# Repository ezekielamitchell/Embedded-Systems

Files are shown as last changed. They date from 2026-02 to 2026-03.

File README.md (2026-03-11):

# REDHAWK ESP32 Robot

Custom PCB-based robot designed and built for the Seattle University Embedded Systems & Design course. The board centers on an ESP32 microcontroller and includes motor drive, quadrature encoders, distance sensing, line following, ambient light sensing, audio output, and Wi-Fi. This repository contains the full KiCad hardware design, power-on functional test firmware, and supporting documentation.

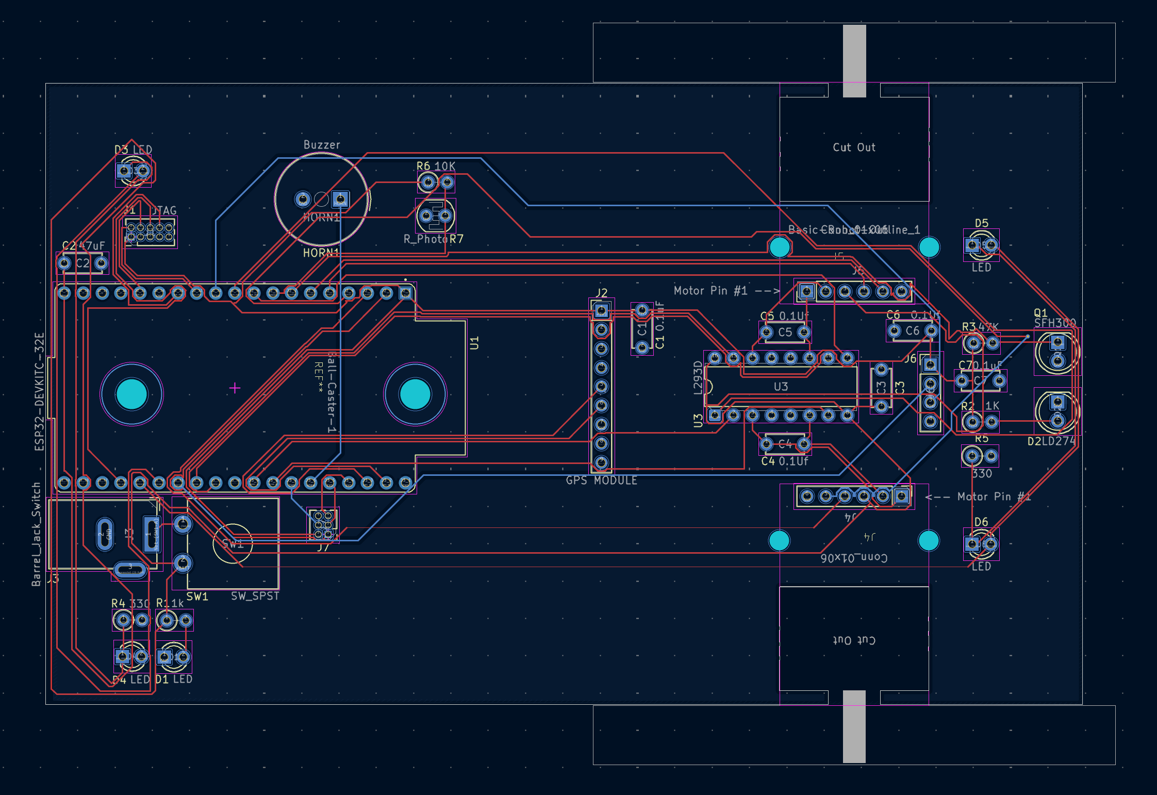
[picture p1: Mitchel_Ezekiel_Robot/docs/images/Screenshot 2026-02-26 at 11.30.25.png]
PCB Layout


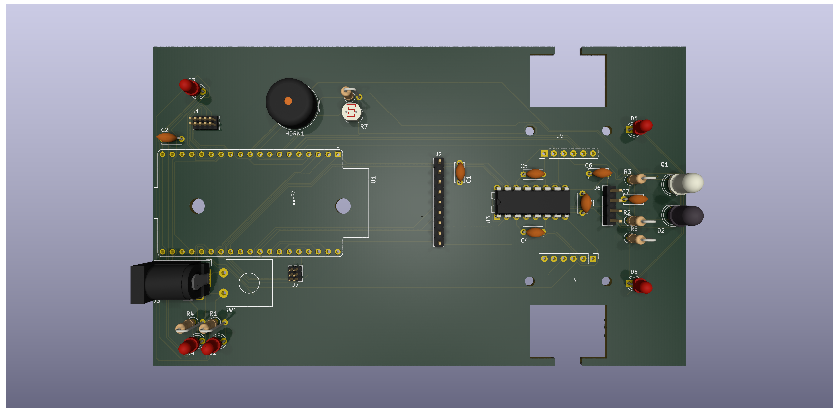
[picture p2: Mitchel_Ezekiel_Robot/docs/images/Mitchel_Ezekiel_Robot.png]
PCB 3D Render — Top


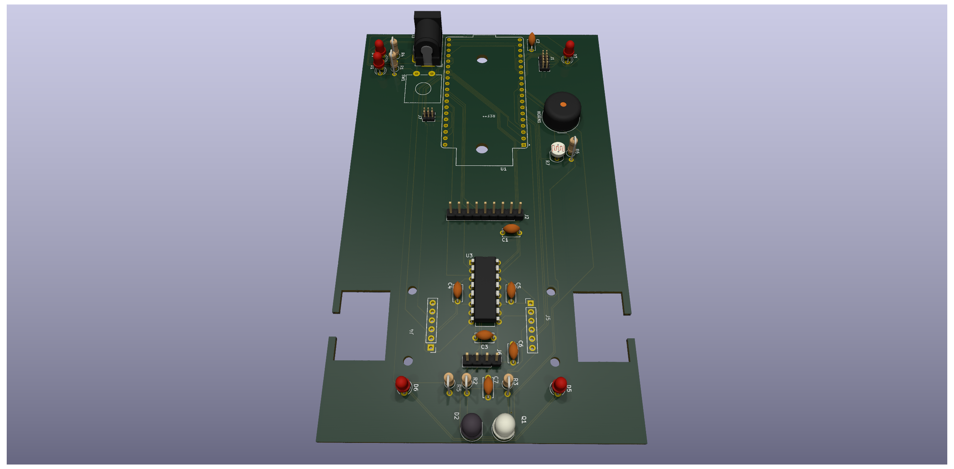
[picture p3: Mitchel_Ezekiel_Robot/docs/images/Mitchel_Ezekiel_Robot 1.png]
PCB 3D Render — Perspective


---

## Repository Structure

```
Embedded-Systems/
├── Mitchel_Ezekiel_Robot/       # KiCad PCB and schematic project
├── PowerOn_Functional_Test/     # PlatformIO firmware — hardware self-test
└── Interrupts/                  # Interrupt lab (placeholder)
```

---

## PCB Design

KiCad 9.0 project containing the full schematic and two-layer PCB layout.

```
Mitchel_Ezekiel_Robot/
├── Mitchel_Ezekiel_Robot.kicad_pcb
├── Mitchel_Ezekiel_Robot.kicad_sch
├── Mitchel_Ezekiel_Robot.kicad_pro
├── Mitchel_Ezekiel_Robot.kicad_prl
├── Ezekiel_Mitchell_ESP32_Robot_Schematic.kicad_pro
├── sym-lib-table
├── docs/
│   ├── ESP32EmeddedRobot_Design-GetStarted-v00-1-10-2025a.pdf
│   └── images/
├── deliverables/
│   └── Ezekiel_Mitchell_ESP32_Robot_Schematic.kicad_sch
└── downloadables/
    ├── 0-My_Library.kicad_sym
    └── 0-My-Library.pretty/
```

### Hardware Overview

#### Microcontroller

| Part | Description |
|---|---|
| ESP32-DEVKITC-32E (U1) | Main MCU — dual-core Xtensa LX6, Wi-Fi + Bluetooth |

#### Motor Drive

| Part | Description |
|---|---|
| L293D (U3) | Dual H-bridge motor driver (DIP-16) |
| Pololu-3675 | Gear motors with quadrature encoders (x2) |
| Pololu-2691 / Ball-Caster-1 | Ball caster (rear support) |

#### Sensors and I/O

| Part | Description |
|---|---|
| R7 — R_Photo | LDR photoresistor (ambient light sensing) |
| D2 — LD274 | IR LED emitter (line detection) |
| Q1 — SFH300 | IR phototransistor receiver |
| HC-SR04 | Ultrasonic distance sensor (TRIG / ECHO) |
| HORN1 — Buzzer | Audio feedback (TDK PS1240P02BT) |
| D1, D3-D6 — LED | Status indicator LEDs (x5, 3 mm) |
| SW1 — SW_SPST | Tactile on/off switch |

#### Communication and Debug

| Part | Description |
|---|---|
| J2 — GPS MODULE | GPS module connector (UART: GPS_TX / GPS_RX) |
| J1 — JTAG | 1.27 mm 2x5 JTAG/SWD debug header |

#### Connectors

| Ref | Value | Description |
|-----|---|---|
| J3 | Barrel_Jack_Switch | Battery input (horizontal barrel jack) |
| J4 | Conn_01x06 | General 6-pin header |
| J5 | Conn_01x06 | General 6-pin header |
| J6 | Conn_01x04 | General 4-pin header |
| J7 | Conn_02x03_Odd_Even | Motor / encoder connector (2x3) |

#### Passives and Power

| Ref | Value | Notes |
|-----|---|---|
| C1, C5-C7 | 0.1 uF | Decoupling capacitors |
| C2, C3 | 47 uF | Bulk filter capacitors |
| R1, R2 | 1 kOhm | Pull-up / current limiting |
| R3 | 47 kOhm | Pull-up for IR receiver circuit |
| R4, R5 | 330 Ohm | LED current limiting |
| R6 | 10 kOhm | Voltage divider (LDR / sensor bias) |

Power rails: `+BATT` (battery input), `+3V3` (regulated 3.3 V from ESP32 module)

### PCB Net Classes

| Net Class | Track Width | Via Diameter | Via Drill | Notes |
|---|---|---|---|---|
| Power | 0.5 mm | 1.0 mm | 0.5 mm | VCC, GND rails |
| Motor | 0.8 mm | 1.2 mm | 0.6 mm | H-bridge output lines |
| High Speed / GPS | 0.2 mm | 0.8 mm | 0.4 mm | GPS UART, high-frequency signals |
| Default | 0.2 mm | 0.8 mm | 0.3 mm | General signals |

### Custom Libraries

Symbol library: `downloadables/0-My_Library.kicad_sym`
Footprint library: `downloadables/0-My-Library.pretty/`

Included footprints:

- `MODULE_ESP32-DEVKITC-32E`
- `Pololu-3675-GearMotorWEncoder`
- `Pololu-2691-Ball_Caster` / `Ball-Caster-1`
- `Basic-Robot-Outline_1`
- ECE capacitive and piano touch switch footprints
- `BAT_2481`, `TRIM_PTA3043-2015DPA104`, and others

### Getting Started (PCB)

1. Install [KiCad 9.0](https://www.kicad.org/)
2. Clone this repository
3. Open `Mitchel_Ezekiel_Robot/Mitchel_Ezekiel_Robot.kicad_pro` in KiCad
4. Register the custom libraries in KiCad's library manager:
   - Footprint: `downloadables/0-My-Library.pretty`
   - Symbol: `downloadables/0-My_Library.kicad_sym`
5. Refer to `docs/ESP32EmeddedRobot_Design-GetStarted-v00-1-10-2025a.pdf` for the original design brief

---

## Power-On Functional Test Firmware

PlatformIO/Arduino firmware that exercises every major peripheral in a fixed sequential test sequence. Flash once and observe the serial monitor for pass/fail output. Tests run in `setup()`; `loop()` serves the Wi-Fi web control interface.

```
PowerOn_Functional_Test/
├── platformio.ini       # PlatformIO config (espressif32 >= 6.0.0)
└── src/
    ├── config.h         # Pin definitions, PWM parameters, Wi-Fi credentials
    ├── main.cpp         # Test sequence and hardware helpers
    ├── web_control.h    # Web server public API
    └── web_control.cpp  # HTTP route handlers and web control page
```

### Prerequisites

| Requirement | Details |
| --- | --- |
| PlatformIO | [platformio.org](https://platformio.org) or VS Code extension |
| ESP32-DevKitC | Connected via USB |
| Arduino-ESP32 core v3.x | Pulled in automatically by `espressif32@^6.0.0` |
| Assembled robot PCB | Motors, LEDs, horn, and sensors populated |

### Pin Map

| Signal | GPIO | Notes |
| --- | ---- | ----- |
| Right Motor 1A / 2A | 18, 19 | L293D direction pins |
| Right Motor EN1 (PWM) | 26 | L293D enable — speed control |
| Left Motor 3A / 4A | 16, 17 | L293D direction pins |
| Left Motor EN3 (PWM) | 25 | L293D enable — speed control |
| Right Encoder A / B | 36, 39 | Input-only GPIOs, INPUT_PULLUP |
| Left Encoder A / B | 34, 35 | Input-only GPIOs, INPUT_PULLUP |
| Horn (piezo) | 21 | PWM — 1 kHz, 50% duty |
| Front LEDs | 2 | Bootstrap pin, safe as output after boot |
| Rear LEDs | 0 | Bootstrap pin, safe as output after boot |
| Photoresistor | 33 | ADC1_CH5 — 12-bit analog input |
| IR Line Sensor | 32 | Digital input |
| Ultrasonic TRIG / ECHO | 4, 27 | HC-SR04 |
| Status LED | 5 | Blinks during Wi-Fi connect, solid when connected |

### Test Sequence

| # | Test | Description | Pass Criteria |
|---|---|---|---|
| 1 | Horn | 5 slow beeps (400 ms on / 300 ms off) | Audible beeps |
| 2 | Front LEDs | 5 blinks on GPIO 2 | Visible flashes |
| 3 | Rear LEDs | 5 blinks on GPIO 0 | Visible flashes |
| 4 | Left Motor | Forward at 100% duty for 1 s | Wheel spins |
| 5 | Right Motor | Forward at 100% duty for 1 s | Wheel spins |
| 6 | Ultrasonic | 5 distance readings via HC-SR04 | At least one valid echo |
| 7 | IR / Line Sensor | Waits up to 10 s for signal transition (user interaction) | Transition detected |
| 8 | Photoresistor | 60 s day/night monitor — lamps follow light level (user interaction) | Lamps respond |
| 9 | Completion | 15 fast beeps as end-of-test signal | Audible beeps |
| EC | Wi-Fi + Web Server | Connects to configured SSID; starts HTTP control page | IP printed to serial |

Tests 7 and 8 require manual interaction. Listen for the two-beep prompt before covering or uncovering the respective sensor.

The web control page (extra credit) is served at the board's IP address after Wi-Fi connects. It displays test results and provides buttons to trigger the horn, toggle LEDs, and drive the motors.

### Build and Flash

Set Wi-Fi credentials in `src/config.h` before flashing:

```cpp
#define WIFI_SSID "your-network-name"
#define WIFI_PASS "your-password"
```

```bash
pio run                   # build
pio run --target upload   # build and flash
pio device monitor        # serial monitor at 115200 baud
```

VS Code: use the PlatformIO toolbar — Build, Upload, Monitor.

---

## Author

Ezekiel Mitchell — Seattle University, Embedded Systems & Design

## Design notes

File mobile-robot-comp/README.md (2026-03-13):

# Robot Firmware — Combined

Unified firmware for the REDHAWK ESP32 robot. Covers all functional tests, a Wi-Fi web control panel for driver mode, and two autonomous modes (line following + maze speed run).

> **Course:** ECEGR 3210 — Embedded Systems & Design, Seattle University, March 2026
> **Author:** Ezekiel A. Mitchell

---

## Features at a Glance

| Feature | Description |
| --- | --- |
| 7 Functional Tests | Horn, LEDs, Light Sensor, Motors, Line Sensor, Ultrasonic, Completion |
| Driver Mode | Hold-to-drive web UI with speed slider and live sensor panel |
| Line Follow (Autonomous) | Single-sensor left-edge follower — BANN 201 circuit |
| Maze Solve (Autonomous) | Right-hand-rule with front ultrasonic — BANN 207 speed run |
| Serial Menu | Full test and mode control at 115200 baud |

---

## Prerequisites

| Requirement | Details |
| --- | --- |
| **PlatformIO** | VS Code extension or CLI from [platformio.org](https://platformio.org) |
| **ESP32-DevKitC** | Connected via USB |
| **arduino-esp32 v3.x** | Pulled in automatically by `espressif32@^6.0.0` in `platformio.ini` |
| **Assembled robot PCB** | Motors, LEDs, horn, and all sensors populated and wired |

---

## Project Structure

```text
PowerOn_Functional_Test/
├── platformio.ini        PlatformIO project config
└── src/
    ├── config.h          Pin assignments, PWM constants, autonomous tuning
    ├── web_control.h     Shared RobotMode enum + extern declarations
    ├── web_control.cpp   All HTTP route handlers and unified web UI
    └── main.cpp          Motor helpers, test functions, autonomous algorithms
```

---

## Hardware & Pin Map

| Signal | GPIO | Direction | Notes |
| --- | --- | --- | --- |
| Right Motor 1A | 18 | Output | L293D pin 2 — direction |
| Right Motor 2A | 19 | Output | L293D pin 7 — direction |
| Right Motor EN1 (PWM) | 26 | Output | L293D pin 1 — speed, LEDC ch 1 |
| Left Motor 3A | 16 | Output | L293D pin 10 — direction |
| Left Motor 4A | 17 | Output | L293D pin 15 — direction |
| Left Motor EN3 (PWM) | 25 | Output | L293D pin 9 — speed, LEDC ch 2 |
| Right Encoder A / B | 36, 39 | Input | Input-only GPIOs, INPUT_PULLUP |
| Left Encoder A / B | 34, 35 | Input | Input-only GPIOs, INPUT_PULLUP |
| Horn (piezo) | 21 | Output | PWM 1 kHz, 50% duty, LEDC ch 0 |
| Front LEDs | 2 | Output | Bootstrap pin — safe after boot |
| Rear LEDs | 0 | Output | Bootstrap pin — safe after boot |
| Light Sensor (LDR) | 33 | Analog In | ADC1_CH5, 12-bit (0–4095) |
| IR Line Sensor | 32 | Digital In | LOW = on black line (default) |
| Ultrasonic TRIG | 4 | Output | HC-SR04 trigger |
| Ultrasonic ECHO | 27 | Input | HC-SR04 echo |
| Status LED | 5 | Output | Solid = Wi-Fi connected |

---

## Configuration

All pin assignments and tuning constants are in `src/config.h`.

**Wi-Fi credentials:**

```cpp
#define WIFI_SSID "SU-ECE-LAB"
#define WIFI_PASS "FaraDay8086!"
```

**Autonomous tuning** (adjust to match your robot's physical characteristics):

```cpp
#define LINE_DETECT_LEVEL  0      // 0 = LOW over line, 1 = HIGH over line
#define SPEED_SLOW        140     // Motor duty 0-255
#define SPEED_MED         180
#define SPEED_FAST        220
#define SPEED_TURN        155
#define LF_STRAIGHT_MS     60     // Line follow: drive time while on-line
#define LF_SEARCH_MS      220     // Line follow: search turn time
#define WALL_STOP_CM       18     // Maze: obstacle threshold (cm)
#define TURN_90_MS        430     // Maze: pivot duration for ~90° at SPEED_TURN
#define WEB_WATCHDOG_MS   600     // Driver: stop if no web command in this window
```

---

## Build & Flash

```bash
pio run                          # Build only
pio run --target upload          # Build and flash
pio device monitor               # Open serial monitor (115200 baud)
```

Or use the PlatformIO toolbar in VS Code: **Build → Upload → Monitor**.

---

## Operating Modes

The firmware uses a mode state machine. Only one mode is active at a time. Any mode switch stops the motors first.

```text
MODE_IDLE        Motors stopped, waiting for input
MODE_MANUAL      Web/serial driver control, 600 ms watchdog
MODE_LINE_FOLLOW Autonomous line following algorithm
MODE_MAZE_SOLVE  Autonomous maze navigation algorithm
```

Switch modes via the **web UI** or the **serial menu** (`M / L / Z / S`).

---

## Web Control UI

After connecting to `SU-ECE-LAB`, the robot prints its IP address to serial:

```text
Connected → open http://192.168.x.x/ in your browser or phone.
```

The single-page UI has five sections:

### Mode Selection Panel

Four buttons: **Manual**, **Line Follow**, **Maze Solve**, **Stop**. Switching modes stops the motors immediately.

### Driver Controls Panel

Directional pad (Forward / Left / Stop / Right / Reverse) with a speed slider (80–255).
Hold a direction button to drive continuously — JavaScript sends a repeat request every 380 ms. Releasing the button sends a stop command. A 600 ms server-side watchdog also stops the motors if the connection drops.

### Quick Controls Panel

**Horn**, **LEDs On**, **LEDs Off** — available in any mode.

### Tests Panel

Individual buttons for Tests 1–6, plus **Run All Tests**. Triggering a test automatically switches to `MODE_IDLE` and stops the motors first.

> Tests 3 (Light Sensor) and 5 (Line Sensor) are blocking and take up to 10 seconds. The web server will not respond during this time.

### Live Sensors Panel

Polls `/sensors` every 1.8 seconds and displays:

- Current mode
- IR line sensor value and on/off-line status
- Light sensor ADC value
- Ultrasonic distance (cm)

---

## Serial Menu

Open the serial monitor at **115200 baud**. The menu is shown on boot and after every command:

```text
╔══════════════════════════════╗
║       Robot Serial Menu      ║
╠══════════════════════════════╣
║  1-6  Run individual test    ║
║  A    Run all tests          ║
║  M    Manual (web driver)    ║
║  L    Line-follow mode       ║
║  Z    Maze-solve mode        ║
║  S    Stop / idle            ║
╚══════════════════════════════╝
```

| Key | Action |
| --- | --- |
| `1` – `6` | Run the corresponding functional test |
| `A` | Clear results and run all tests in sequence |
| `M` | Switch to Manual driver mode |
| `L` | Start autonomous line-follow mode (2 beeps) |
| `Z` | Start autonomous maze-solve mode (3 beeps) |
| `S` | Stop all motion, return to idle |

---

## Functional Tests

All tests run in sequence via **Run All** or can be triggered individually. Results are stored in `testResults` and displayed on the web page.

### Test 1 — Horn

Emits 5 beeps (400 ms on / 300 ms off) via the piezo on GPIO 21.
**Pass:** 5 audible beeps, serial shows `PASS`.

### Test 2 — LEDs

Front/rear alternating (3 cycles × 400 ms), then all on (500 ms), then all off.
**Pass:** LEDs follow the sequence, serial shows `PASS`.

### Test 3 — Light Sensor *(requires interaction)*

Samples a 10-reading baseline, then monitors GPIO 33 for 10 seconds. Cover/uncover the photoresistor during the window. Both LED banks activate when the reading deviates from baseline by more than ±200 ADC counts.
**Pass:** ADC values change visibly, serial shows `[DARK]`/`[LIGHT]` labels and `PASS`.

### Test 4 — Motors

Left forward → left reverse → right forward → right reverse, 1 second each with 300 ms pauses.
**Pass:** Each motor spins the correct direction, serial shows `PASS`.

### Test 5 — Line Sensor *(requires interaction)*

Reads GPIO 32 and waits up to 10 seconds for any state change. Place or remove an object over the IR sensor during the window.
**Pass:** Serial shows `Transition detected - PASS`.

### Test 6 — Ultrasonic

Fires the HC-SR04 five times and prints distances to serial.
**Pass:** At least one reading returns a non-zero distance.

### Test 7 — Completion

15 fast beeps (80 ms on / 60 ms off) as an audible end-of-sequence fanfare.

---

## Autonomous Modes

### Line Follow — BANN 201

**Algorithm:** Single-sensor left-edge follower using the IR sensor on GPIO 32.

| Sensor state | Action |
| --- | --- |
| On line (LOW) | `curveRight` at `SPEED_MED` for `LF_STRAIGHT_MS` |
| Off line (HIGH) | `curveLeft` at `SPEED_MED` for `LF_SEARCH_MS` |

The robot tracks the left edge of the black line, producing a controlled zig-zag. The short step delays keep the web server responsive between iterations.

**To activate:** Press **Line Follow** on the web UI, or send `L` via serial.
**To stop:** Press **Stop** on the web UI, or send `S` via serial.

**Line follow tuning tips:**

- If the robot overshoots and loses the line: decrease `LF_SEARCH_MS`.
- If it barely curves: increase `LF_STRAIGHT_MS` or decrease `SPEED_MED`.
- If the sensor polarity is inverted on your hardware: change `LINE_DETECT_LEVEL` to `1`.

---

### Maze Solve — BANN 207

**Algorithm:** Right-hand-rule using the front HC-SR04 ultrasonic sensor.

```text
1. Drive forward at MAZE_SPEED.
2. Obstacle detected ≤ WALL_STOP_CM → stop, pivot right ~90°.
3. Recheck; if still blocked repeat step 2.
4. After 8 consecutive blocked turns → reverse 500 ms (stuck recovery), reset counter.
```

**To activate:** Press **Maze Solve** on the web UI, or send `Z` via serial.
**To stop:** Press **Stop** on the web UI, or send `S` via serial.

**Maze solve tuning tips:**

- Adjust `WALL_STOP_CM` to change how close the robot gets to a wall before turning.
- Adjust `TURN_90_MS` if the robot over- or under-rotates on turns (measured at `SPEED_TURN = 155`).
- Narrow corridors may need a shorter `WALL_STOP_CM` (e.g. `12`).

---

## Communication & Protocols

| Protocol | Interface | Pins | Purpose |
| --- | --- | --- | --- |
| UART / Serial | USB (built-in) | — | Debug output and serial menu at 115200 baud |
| Wi-Fi 802.11 b/g/n | RF | Antenna | Station mode — joins `SU-ECE-LAB` |
| HTTP / TCP port 80 | Over Wi-Fi | — | Web control UI, sensor endpoint, mode/drive/test routes |
| PWM (LEDC) | Hardware peripheral | 21, 25, 26 | Horn tone (1 kHz) and motor speed (5 kHz) |
| GPIO Digital | I/O | 0,2,4,16–19,27,32 | Motor direction, LEDs, ultrasonic TRIG/ECHO, IR sensor |
| ADC (12-bit SAR) | Hardware peripheral | 33 | Ambient light sensor (0–4095) |
| HC-SR04 Pulse | 2-wire custom | 4 (TRIG), 27 (ECHO) | Time-of-flight distance measurement |

---

## HTTP Routes

| Route | Method | Description |
| --- | --- | --- |
| `/` | GET | Full HTML control page |
| `/sensors` | GET | Live sensor snapshot (plain text) |
| `/drive/{fwd\|rev\|left\|right\|stop}?spd=N` | GET | Driver mode motor command |
| `/mode/{idle\|manual\|line\|maze}` | GET | Switch operating mode |
| `/test/{1–6\|all}` | GET | Trigger a functional test |
| `/horn` | GET | Single horn beep |
| `/leds/on` | GET | Turn both LED banks on |
| `/leds/off` | GET | Turn both LED banks off |

---

## Test Plan Coverage

| # | Requirement | Status | Notes |
| --- | --- | --- | --- |
| 1 | Horn — audible on/off | **PASS** | 5 beeps, 400 ms / 300 ms |
| 2 | LEDs — front/rear alternating, all on, all off | **PASS** | 3 alternating cycles then full on/off |
| 3 | Light sensor — ADC stream under dark/bright/normal | **PASS** | Readings every 500 ms, `[DARK]`/`[LIGHT]` labels |
| 4 | Motors — fwd/rev each motor independently | **PASS** | Left then right, 1 s each direction |
| 5 | Line sensor — detect line vs. background | **PASS** | Digital transition detected within 10 s window |
| 6 | Ultrasonic — distance readings change | **PASS** | 5 readings printed to serial |
| 7 | Serial menu — run each test independently | **PASS** | Keys `1–6`, `A`, `M`, `L`, `Z`, `S` |
| EC | Wi-Fi + web browser/phone control | **PASS** | Full web UI on port 80 |
| EC | Line Following — BANN 201 | **PASS** | Autonomous left-edge follower |
| EC | Maze Speed Run — BANN 207 | **PASS** | Autonomous right-hand-rule solver |

---

## Troubleshooting

| Symptom | Likely Cause |
| --- | --- |
| Upload fails | Wrong COM port; hold BOOT + tap EN to enter bootloader |
| `ledcSetup` compile errors | Wrong core version — confirm `espressif32@^6.0.0` |
| Horn silent | Piezo not on GPIO 21; LEDC channel conflict |
| Motors don't spin | Motor supply missing; L293D direction/enable wiring wrong |
| IR sensor never changes | GPIO 32 floating or sensor not wired; no interaction during window |
| ADC reads 0 or 4095 | LDR open/short circuit; R6 bias resistor missing |
| Robot spins in place (line follow) | `LINE_DETECT_LEVEL` has wrong polarity; increase `LF_SEARCH_MS` |
| Maze robot won't turn | `WALL_STOP_CM` too small for the environment; increase it |
| Wi-Fi timeout | Wrong SSID/password in `config.h`; network out of range |
| Web driver jittery | Network latency; widen `WEB_WATCHDOG_MS` slightly |

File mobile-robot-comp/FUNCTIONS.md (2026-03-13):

# Function Reference — Robot Firmware (Combined)

Detailed documentation of every function, its parameters, internal logic, and side effects across all source files.

---

## Table of Contents

- [config.h — Pin, PWM & Tuning Constants](#configh--pin-pwm--tuning-constants)
- [web\_control.h — Public Interface & Shared State](#web_controlh--public-interface--shared-state)
- [main.cpp — Core Firmware](#maincpp--core-firmware)
  - UDP: [`dance`](#dance) · [`handleCommand`](#handlecommand)
  - Motor Helpers: [`motorsStop`](#motorsstop) · [`driveForward`](#driveforward) · [`driveReverse`](#drivereverse) · [`pivotLeft`](#pivotleft) · [`pivotRight`](#pivotright) · [`curveLeft`](#curveleft) · [`curveRight`](#curveright)
  - Sensor Helpers: [`onLine`](#online) · [`readUltrasonic`](#readultrasonic)
  - Horn: [`beep`](#beep)
  - Utility: [`blinkLamp`](#blinklamp)
  - Functional Tests: [`testHorn`](#testhorn) · [`testLEDs`](#testleds) · [`testLightSensor`](#testlightsensor) · [`testMotors`](#testmotors) · [`testLineSensor`](#testlinesensor) · [`testUltrasonic`](#testultrasonic) · [`runAllTests`](#runalltests)
  - Autonomous Modes: [`runLineFollow`](#runlinefollow) · [`runMazeSolve`](#runmazesolve)
  - Serial Menu: [`printMenu`](#printmenu) · [`handleSerial`](#handleserial)
  - Arduino Entry Points: [`setup`](#setup) · [`loop`](#loop)
- [web\_control.cpp — HTTP Server](#web_controlcpp--http-server)
  - [`handleRoot`](#handleroot) · [`handleSensors`](#handlesensors)
  - [`handleDrive`](#handledrive) · [`handleMode`](#handlemode) · [`handleTest`](#handletest)
  - [`handleHorn`](#handlehorn) · [`handleLedsOn`](#handleledson) · [`handleLedsOff`](#handleledsoff)
  - [`setupWebServer`](#setupwebserver) · [`webServerLoop`](#webserverloop)
- [Data Flow Summary](#data-flow-summary)
- [Author](#author)

---

## config.h — Pin, PWM & Tuning Constants

All values are `#define` macros resolved at compile time. Nothing is runtime-configurable from this file.

### Pin Assignments

| Macro | GPIO | Purpose |
| --- | --- | --- |
| `RMOTOR_1A` | 18 | Right motor direction A (L293D input 1) |
| `RMOTOR_2A` | 19 | Right motor direction B (L293D input 2) |
| `RPWM_1A2A` | 26 | Right motor PWM speed (L293D enable 1) |
| `LMOTOR_3A` | 16 | Left motor direction A (L293D input 3) |
| `LMOTOR_4A` | 17 | Left motor direction B (L293D input 4) |
| `LPWM_3A4A` | 25 | Left motor PWM speed (L293D enable 3) |
| `RENCODER_A/B` | 36, 39 | Right wheel quadrature encoder (input-only) |
| `LENCODER_A/B` | 34, 35 | Left wheel quadrature encoder (input-only) |
| `HORN` | 21 | Piezo buzzer output |
| `FRONTLAMPS` | 2 | Front LED network (bootstrap pin, safe after boot) |
| `REARLAMPS` | 0 | Rear LED network (bootstrap pin, safe after boot) |
| `DAYNIGHT` | 33 | Photoresistor ADC input (ADC1_CH5, 12-bit) |
| `IR_RECEIVE` | 32 | IR line sensor digital input |
| `TRIG` | 4 | HC-SR04 ultrasonic trigger output |
| `ECHO` | 27 | HC-SR04 ultrasonic echo input |
| `STATUS_LED` | 5 | Status LED — solid when Wi-Fi connected |

### PWM / LEDC Constants

| Macro | Value | Purpose |
| --- | --- | --- |
| `HORN_CH` | 0 | LEDC channel for horn |
| `RMOTOR_CH` | 1 | LEDC channel for right motor |
| `LMOTOR_CH` | 2 | LEDC channel for left motor |
| `HORN_FREQ` | 1000 | Horn frequency (Hz) |
| `HORN_RES` | 8 | Horn PWM resolution (bits) |
| `HORN_DUTY` | 128 | Horn duty cycle (~50%) |
| `MOTOR_FREQ` | 5000 | Motor PWM frequency (Hz) |
| `MOTOR_RES` | 8 | Motor PWM resolution (bits) |
| `MOTOR_FULL_DUTY` | 255 | 100% duty cycle (8-bit max) |

### Autonomous Mode Tuning

| Macro | Value | Purpose |
| --- | --- | --- |
| `LINE_DETECT_LEVEL` | 0 | Sensor polarity: `0` = LOW over black line, `1` = HIGH over black line |
| `SPEED_SLOW` | 140 | Motor duty for slow movement |
| `SPEED_MED` | 180 | Motor duty for moderate movement |
| `SPEED_FAST` | 220 | Motor duty for fast movement |
| `SPEED_TURN` | 155 | Motor duty used during pivot turns |
| `LF_STRAIGHT_MS` | 60 | Line follow: drive time (ms) while sensor is on the line |
| `LF_SEARCH_MS` | 220 | Line follow: search turn time (ms) when sensor loses the line |
| `MAZE_SPEED` | `SPEED_FAST` | Maze solver: forward drive speed |
| `WALL_STOP_CM` | 18 | Maze solver: obstacle distance threshold (cm) |
| `TURN_90_MS` | 430 | Maze solver: pivot duration (ms) for ~90° at `SPEED_TURN` |
| `WEB_WATCHDOG_MS` | 600 | Driver mode: stop motors if no `/drive` command received in this window |

### Wi-Fi Credentials

| Macro | Value |
| --- | --- |
| `WIFI_SSID` | `"SU-ECE-LAB"` |
| `WIFI_PASS` | `"FaraDay8086!"` |
| `AP_SSID` | `"ezekielRobot"` |
| `AP_PASS` | `"password123"` |

---

## web_control.h — Public Interface & Shared State

Declares the `RobotMode` enum and all shared variables that `main.cpp` and `web_control.cpp` exchange at runtime.

### `RobotMode` enum

```cpp
enum RobotMode { MODE_IDLE, MODE_MANUAL, MODE_LINE_FOLLOW, MODE_MAZE_SOLVE };
```

| Value | Meaning |
| --- | --- |
| `MODE_IDLE` | Motors stopped, no autonomous algorithm running |
| `MODE_MANUAL` | Web/serial driver control; watchdog active |
| `MODE_LINE_FOLLOW` | `runLineFollow()` called every `loop()` iteration |
| `MODE_MAZE_SOLVE` | `runMazeSolve()` called every `loop()` iteration |

### Shared `extern` variables

| Variable | Type | Owner | Purpose |
| --- | --- | --- | --- |
| `robotMode` | `volatile RobotMode` | `web_control.cpp` | Current operating mode; read by `loop()`, written by web handlers and `handleSerial()` |
| `webSpeed` | `volatile int` | `web_control.cpp` | Motor duty cycle set by the speed slider (0–255); read by `handleDrive()` |
| `lastWebCmd` | `volatile unsigned long` | `web_control.cpp` | `millis()` timestamp of the most recent `/drive` request; used by the watchdog in `loop()` |
| `testResults` | `String` | `main.cpp` | Accumulated pass/fail text; injected into the web page by `handleRoot()` |

---

## main.cpp — Core Firmware

---

### UDP Globals

| Symbol | Type | Value | Purpose |
| --- | --- | --- | --- |
| `robotID` | `int` | `3` | Unique robot identifier; checked against the numeric suffix in `DANCE_<id>` commands |
| `UDP_PORT` | `#define` | `4210` | UDP port number the robot listens on for instructor broadcast commands |
| `udp` | `WiFiUDP` | — | Arduino UDP socket object; opened with `udp.begin(UDP_PORT)` in `setup()` |
| `incomingPacket` | `char[255]` | — | Receive buffer for incoming UDP datagrams; null-terminated after each read |

---

### `dance()`

```cpp
void dance()
```

Performs a visual + audible dance routine triggered by a UDP broadcast command.

Runs 6 cycles (×400 ms each = ~2.4 s total):

1. `FRONTLAMPS` HIGH, `REARLAMPS` LOW, horn on (`HORN_CH` at `HORN_DUTY`) for 200 ms.
2. `FRONTLAMPS` LOW, `REARLAMPS` HIGH, horn off for 200 ms.

After the loop, `REARLAMPS` is driven `LOW` to leave both LED banks off.

Prints `"Robot Dancing!"` to serial at the start.

**Called by:** `handleCommand()`.

---

### `handleCommand()`

```cpp
void handleCommand(String cmd)
```

Parses a UDP command string and dispatches the appropriate action.

| Command | Condition | Action |
| --- | --- | --- |
| `"DANCE_ALL"` | Always | Calls `dance()` |
| `"DANCE_<N>"` | `N == robotID` | Calls `dance()`; ignored if `N` does not match |

Both checks are independent `if` statements, so `"DANCE_ALL"` triggers dance once regardless of `robotID`.

**Called by:** `loop()` when a UDP packet is received.

---

### `motorsStop()`

```cpp
void motorsStop()
```

Brings both motors to an immediate coast stop.

1. Writes `0` to both `RMOTOR_CH` and `LMOTOR_CH` — removes all PWM drive.
2. Sets all four direction pins (`RMOTOR_1A`, `RMOTOR_2A`, `LMOTOR_3A`, `LMOTOR_4A`) `LOW` — neutral state on the L293D H-bridge.

**Used by:** `setup()`, all test functions that run motors, `handleSerial()`, `handleDrive()`, `handleMode()`, `handleTest()`, `runMazeSolve()`.

---

### `driveForward()`

```cpp
void driveForward(int spd)
```

Drives both wheels forward at duty cycle `spd` (0–255).

Sets `RMOTOR_1A` / `LMOTOR_3A` HIGH and `RMOTOR_2A` / `LMOTOR_4A` LOW on both channels, then writes `spd` to both PWM channels.

---

### `driveReverse()`

```cpp
void driveReverse(int spd)
```

Drives both wheels in reverse at duty cycle `spd`.

Inverts the direction pins relative to `driveForward()`: `RMOTOR_1A` / `LMOTOR_3A` LOW, `RMOTOR_2A` / `LMOTOR_4A` HIGH.

---

### `pivotLeft()`

```cpp
void pivotLeft(int spd)
```

Spins the robot left in place. Right wheel drives forward, left wheel drives reverse, both at duty cycle `spd`. Results in a zero-radius left turn.

---

### `pivotRight()`

```cpp
void pivotRight(int spd)
```

Spins the robot right in place. Left wheel drives forward, right wheel drives reverse, both at duty cycle `spd`. Results in a zero-radius right turn.

---

### `curveLeft()`

```cpp
static void curveLeft(int spd)
```

Curves the robot to the left while moving forward. Both wheels drive forward; the left (inner) wheel runs at `spd / 2` and the right (outer) wheel at `spd`. The speed differential produces a gradual arc to the left.

**Used by:** `runLineFollow()` when the sensor is off the line.

---

### `curveRight()`

```cpp
static void curveRight(int spd)
```

Curves the robot to the right while moving forward. Both wheels drive forward; the right (inner) wheel runs at `spd / 2` and the left (outer) wheel at `spd`.

**Used by:** `runLineFollow()` when the sensor is on the line.

---

### `onLine()`

```cpp
static bool onLine()
```

Returns `true` if the IR line sensor currently detects the line.

Reads `IR_RECEIVE` (GPIO 32) and compares to `LINE_DETECT_LEVEL`. If the sensor outputs `LOW` over a black line, set `LINE_DETECT_LEVEL 0`; if it outputs `HIGH`, set it to `1`.

---

### `readUltrasonic()`

```cpp
static long readUltrasonic()
```

Fires the HC-SR04 and returns the measured distance in centimetres. Returns `0` if no echo is received within the 25 ms timeout.

1. Pulls `TRIG` LOW for 2 µs, HIGH for 10 µs, then LOW — the standard trigger sequence.
2. Calls `pulseIn(ECHO, HIGH, 25000UL)` to measure the echo pulse duration in microseconds.
3. Divides by 58 to convert to cm (speed of sound ≈ 340 m/s → 58 µs/cm round trip).

**Used by:** `testUltrasonic()`, `runMazeSolve()`, `handleSensors()`.

---

### `beep()`

```cpp
void beep(int count, int onMs, int offMs)
```

Produces `count` audible tones on the piezo horn.

Each iteration writes `HORN_DUTY` (128) to LEDC channel `HORN_CH` for `onMs` ms, then writes `0` to silence it. If not the last beep, waits `offMs` ms before the next tone.

| Parameter | Description |
| --- | --- |
| `count` | Number of beeps |
| `onMs` | Duration of each beep (ms) |
| `offMs` | Gap between beeps (ms); skipped after the last beep |

---

### `blinkLamp()`

```cpp
static void blinkLamp(int pin, int count, int onMs, int offMs)
```

Blinks a single GPIO pin `count` times. Defined for single-pin blinking; the LED tests drive two pins simultaneously with direct `digitalWrite` calls instead of using this helper.

---

### `testHorn()`

```cpp
void testHorn()
```

**Test 1.** Calls `beep(5, 400, 300)` — five 400 ms tones with 300 ms gaps. Always records PASS (audible verification by the tester).

---

### `testLEDs()`

```cpp
void testLEDs()
```

**Test 2.** Runs three alternating front/rear cycles (400 ms each), then all-on for 500 ms, then all-off. Drives both pins directly with `digitalWrite`. Always records PASS.

---

### `testLightSensor()`

```cpp
void testLightSensor()
```

**Test 3.** Monitors the photoresistor on GPIO 33 for 10 seconds.

1. Beeps twice, then samples 10 ADC readings to establish a baseline.
2. Loops for 10 seconds, sampling every 500 ms.
3. If `abs(reading - baseline) > 200`, activates both LED banks and prints `[DARK]`; otherwise prints `[LIGHT]`.
4. Turns LEDs off and records PASS on timeout.

---

### `testMotors()`

```cpp
void testMotors()
```

**Test 4.** Runs four 1-second phases — left forward, left reverse, right forward, right reverse — with `motorsStop()` and a 300 ms pause between each. Uses `MOTOR_FULL_DUTY` (255) for all phases.

---

### `testLineSensor()`

```cpp
void testLineSensor()
```

**Test 5.** Beeps twice, captures the initial GPIO 32 state, then polls every 50 ms for up to 10 seconds. Records PASS on the first state change; records FAIL if none occurs before the timeout.

---

### `testUltrasonic()`

```cpp
void testUltrasonic()
```

**Test 6.** Calls `readUltrasonic()` five times, printing each distance (or `"no echo"`) to serial with a 200 ms gap between readings. Records PASS if at least one reading is > 0.

---

### `runAllTests()`

```cpp
void runAllTests()
```

Clears `testResults`, then calls Tests 1–6 in sequence. After all pass, calls `beep(15, 80, 60)` as the completion fanfare and appends Test 7 PASS.

---

### `runLineFollow()`

```cpp
static void runLineFollow()
```

**Autonomous line-follow step** — called once per `loop()` iteration while `robotMode == MODE_LINE_FOLLOW`.

Implements a **single-sensor left-edge follower**:

| Sensor state | Action | Delay |
| --- | --- | --- |
| `onLine()` is `true` | `curveRight(SPEED_SLOW)` — steers sensor toward edge | `LF_STRAIGHT_MS` |
| `onLine()` is `false` | `curveLeft(SPEED_SLOW)` — steers back over the line | `LF_SEARCH_MS` |

The robot tracks the left edge of the black line, producing a controlled zig-zag. Short delays keep `webServerLoop()` responsive between steps.

**Starting position:** The IR sensor must start on or near the left edge of the tape. If started fully off the line, the robot will search left until the line is found.

**Tuning:** Adjust `LF_STRAIGHT_MS`, `LF_SEARCH_MS`, and speed in `config.h`. If the robot avoids the line instead of following it, flip `LINE_DETECT_LEVEL`.

---

### `runMazeSolve()`

```cpp
static void runMazeSolve()
```

**Autonomous maze-solve step** — called once per `loop()` iteration while `robotMode == MODE_MAZE_SOLVE`.

Implements a **right-hand-rule** using the front ultrasonic sensor.

| Condition | Action |
| --- | --- |
| No obstacle (`dist > WALL_STOP_CM` or no echo) | `driveForward(MAZE_SPEED)` for 80 ms |
| Obstacle within `WALL_STOP_CM` | Stop, then `pivotRight(SPEED_TURN)` for `TURN_90_MS` |
| Obstacle on 9th consecutive turn (`mazeStuckCount > 8`) | `driveReverse(SPEED_MED)` for 500 ms, reset counter |

`mazeStuckCount` is a file-scope `static int` that resets to `0` whenever a clear path is found or when `handleSerial()` starts the mode. Each blocked turn increments it; the reverse-and-reset recovery prevents infinite spinning in dead ends.

---

### `printMenu()`

```cpp
static void printMenu()
```

Prints the bordered serial menu to the monitor, listing all keys (`1`–`6`, `A`, `M`, `L`, `Z`, `S`), then prints `"Select: "` without a newline to leave the cursor at the prompt.

**Called by:** `setup()` once after boot, and by `handleSerial()` after every command.

---

### `handleSerial()`

```cpp
static void handleSerial()
```

Reads one character from the serial buffer, flushes the rest, and dispatches the command.

For test commands (`1`–`6`, `A`): sets `robotMode = MODE_IDLE` and calls `motorsStop()` first, then calls the appropriate test function.

For mode commands:

| Key | Action |
| --- | --- |
| `M` / `m` | `robotMode = MODE_MANUAL` |
| `L` / `l` | `robotMode = MODE_LINE_FOLLOW`, beeps twice |
| `Z` / `z` | `robotMode = MODE_MAZE_SOLVE`, resets `mazeStuckCount`, beeps three times |
| `S` / `s` | `robotMode = MODE_IDLE` |

Calls `printMenu()` after every command. Returns immediately if no serial data is available.

---

### `setup()`

```cpp
void setup()
```

Arduino entry point. Configures all hardware and connects to Wi-Fi.

**Hardware initialisation:**

- Serial at 115200 baud.
- All motor direction pins, lamp pins, TRIG, and `STATUS_LED` as `OUTPUT`. TRIG and STATUS_LED initialised `LOW`.
- ECHO and `IR_RECEIVE` as `INPUT`; encoder pins as `INPUT_PULLUP`.
- Three LEDC channels configured with `ledcSetup()` and attached with `ledcAttachPin()`.
- All PWM channels zeroed; `motorsStop()` called; ADC resolution set to 12-bit.
- 1-second settling delay.

**Wi-Fi (station mode):**

Connects to `WIFI_SSID` with a 20-second timeout. `STATUS_LED` blinks at 0.5 Hz while connecting:

- **Success:** LED goes solid; IP printed to serial; `setupWebServer()` called; `udp.begin(UDP_PORT)` opens the UDP socket on port 4210.
- **Failure:** LED blinks rapidly for ~4 s, then goes off; firmware continues without a web server or UDP listener.

Unlike the original firmware, tests are **not** run automatically on boot. The serial menu is presented immediately after Wi-Fi setup.

---

### `loop()`

```cpp
void loop()
```

Main execution loop. Runs four things on every iteration:

1. **UDP poll** — calls `udp.parsePacket()`; if a datagram has arrived, reads it into `incomingPacket`, null-terminates it, and passes it to `handleCommand()`.
2. `webServerLoop()` — services pending HTTP requests.
3. `handleSerial()` — processes one serial character if available.
4. Mode dispatch:

| `robotMode` | Action |
| --- | --- |
| `MODE_IDLE` | Nothing |
| `MODE_MANUAL` | Watchdog: calls `motorsStop()` if `millis() - lastWebCmd > WEB_WATCHDOG_MS` |
| `MODE_LINE_FOLLOW` | Calls `runLineFollow()` |
| `MODE_MAZE_SOLVE` | Calls `runMazeSolve()` |

---

## web_control.cpp — HTTP Server

All route handlers are `static` (internal to this translation unit). Shared state (`robotMode`, `webSpeed`, `lastWebCmd`) is defined here and declared `extern` in `web_control.h`. A single `static WebServer server(80)` instance is shared by all functions.

---

### `handleRoot()`

**Route:** `GET /`

Builds and sends the complete HTML control page. The page is assembled from raw-string literals with `testResults` injected at the appropriate point. It contains five sections: Mode Selection, Driver Controls, Quick Controls, Tests, and Live Sensors. JavaScript on the page uses `fetch()` for all button actions (no page reload), and polls `/sensors` every 1.8 seconds.

---

### `handleSensors()`

**Route:** `GET /sensors`

Returns a plain-text sensor snapshot, called by the page's auto-poll every 1.8 s.

1. Fires `TRIG` and measures the HC-SR04 echo.
2. Reads `IR_RECEIVE` and `DAYNIGHT`.
3. Sends a formatted multi-line string: current mode, IR value + on/off-line label, ADC value, and distance.

---

### `handleDrive()`

**Route:** `GET /drive/{fwd|rev|left|right|stop}?spd=N`

Only acts when `robotMode == MODE_MANUAL`; returns an error string otherwise.

Parses the direction from the URI (`server.uri().substring(7)`) and the optional `spd` query parameter (defaults to `webSpeed` if absent, clamped to 0–255). Updates `webSpeed` and `lastWebCmd`, then calls the appropriate motor helper:

| URI segment | Motor call |
| --- | --- |
| `fwd` | `driveForward(spd)` |
| `rev` | `driveReverse(spd)` |
| `left` | `pivotLeft(spd)` |
| `right` | `pivotRight(spd)` |
| `stop` | `motorsStop()` |

The browser holds a direction button → JavaScript sends this request every 380 ms. The server-side watchdog (`WEB_WATCHDOG_MS = 600 ms`) stops the motors if the stream of requests stops.

---

### `handleMode()`

**Route:** `GET /mode/{idle|manual|line|maze}`

Calls `motorsStop()` first (safe transition regardless of current state), then sets `robotMode`:

| URI segment | `robotMode` set to |
| --- | --- |
| `idle` | `MODE_IDLE` |
| `manual` | `MODE_MANUAL` |
| `line` | `MODE_LINE_FOLLOW` |
| `maze` | `MODE_MAZE_SOLVE` |

---

### `handleTest()`

**Route:** `GET /test/{1–6|all}`

Forces `robotMode = MODE_IDLE` and calls `motorsStop()`, then dispatches to the appropriate test function. Blocks until the test completes before sending the HTTP response.

| URI segment | Function called |
| --- | --- |
| `1` | `testHorn()` |
| `2` | `testLEDs()` |
| `3` | `testLightSensor()` |
| `4` | `testMotors()` |
| `5` | `testLineSensor()` |
| `6` | `testUltrasonic()` |
| `all` | `runAllTests()` |

---

### `handleHorn()`

**Route:** `GET /horn`

Calls `beep(3, 150, 100)` then responds `"Beeped!"`. Blocks ~500 ms while beeping.

---

### `handleLedsOn()`

**Route:** `GET /leds/on`

Writes `HIGH` to `FRONTLAMPS` and `REARLAMPS`. Responds `"LEDs ON"`.

---

### `handleLedsOff()`

**Route:** `GET /leds/off`

Writes `LOW` to `FRONTLAMPS` and `REARLAMPS`. Responds `"LEDs OFF"`.

---

### `setupWebServer()`

```cpp
void setupWebServer()
```

Registers all routes with `server.on()` and calls `server.begin()`. Called once from `setup()` if Wi-Fi connects.

| Path | Handler |
| --- | --- |
| `/` | `handleRoot` |
| `/sensors` | `handleSensors` |
| `/drive/fwd` | `handleDrive` |
| `/drive/rev` | `handleDrive` |
| `/drive/left` | `handleDrive` |
| `/drive/right` | `handleDrive` |
| `/drive/stop` | `handleDrive` |
| `/mode/idle` | `handleMode` |
| `/mode/manual` | `handleMode` |
| `/mode/line` | `handleMode` |
| `/mode/maze` | `handleMode` |
| `/test/1` – `/test/6` | `handleTest` |
| `/test/all` | `handleTest` |
| `/horn` | `handleHorn` |
| `/leds/on` | `handleLedsOn` |
| `/leds/off` | `handleLedsOff` |

---

### `webServerLoop()`

```cpp
void webServerLoop()
```

Calls `server.handleClient()` — the ESP32 WebServer library's polling function. Returns immediately if no request is pending. Must be called on every `loop()` iteration to keep the server responsive. Keeping this behind a named function means `main.cpp` does not need to `#include <WebServer.h>`.

---

## Data Flow Summary

```text
setup()
  ├── hardware init (GPIO, LEDC, ADC)
  ├── Wi-Fi STA connect → setupWebServer() if connected
  └── printMenu()

loop()  [runs continuously]
  ├── udp.parsePacket()  [non-blocking]
  │     └── handleCommand()
  │           ├── "DANCE_ALL"     → dance()
  │           └── "DANCE_<id>"   → dance() if id == robotID
  │
  ├── webServerLoop()
  │     └── server.handleClient()
  │           ├── GET /              → handleRoot()       → injects testResults
  │           ├── GET /sensors       → handleSensors()    → live sensor snapshot
  │           ├── GET /drive/*       → handleDrive()      → motor helpers (MANUAL only)
  │           ├── GET /mode/*        → handleMode()       → sets robotMode
  │           ├── GET /test/*        → handleTest()       → calls test functions
  │           ├── GET /horn          → handleHorn()       → beep()
  │           ├── GET /leds/on       → handleLedsOn()
  │           └── GET /leds/off      → handleLedsOff()
  │
  ├── handleSerial()
  │     ├── '1'–'6'  → testXxx()    → appends to testResults
  │     ├── 'A'/'a'  → runAllTests() → appends to testResults
  │     ├── 'M'/'m'  → MODE_MANUAL
  │     ├── 'L'/'l'  → MODE_LINE_FOLLOW
  │     ├── 'Z'/'z'  → MODE_MAZE_SOLVE
  │     └── 'S'/'s'  → MODE_IDLE
  │
  └── mode dispatch
        ├── MODE_IDLE         → nothing
        ├── MODE_MANUAL       → watchdog → motorsStop() if stale
        ├── MODE_LINE_FOLLOW  → runLineFollow()
        │                          onLine() → curveRight / curveLeft
        └── MODE_MAZE_SOLVE   → runMazeSolve()
                                   readUltrasonic() → driveForward / pivotRight / driveReverse
```

---

## Author

**Ezekiel Mitchell** — Seattle University, Embedded Systems & Design

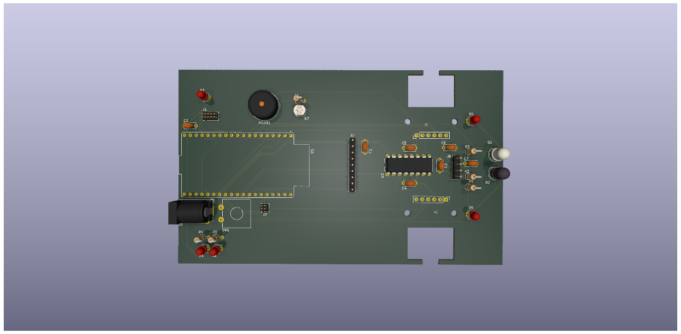
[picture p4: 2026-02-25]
Mitchel_Ezekiel_Robot/Mitchel_Ezekiel_Robot 2.png

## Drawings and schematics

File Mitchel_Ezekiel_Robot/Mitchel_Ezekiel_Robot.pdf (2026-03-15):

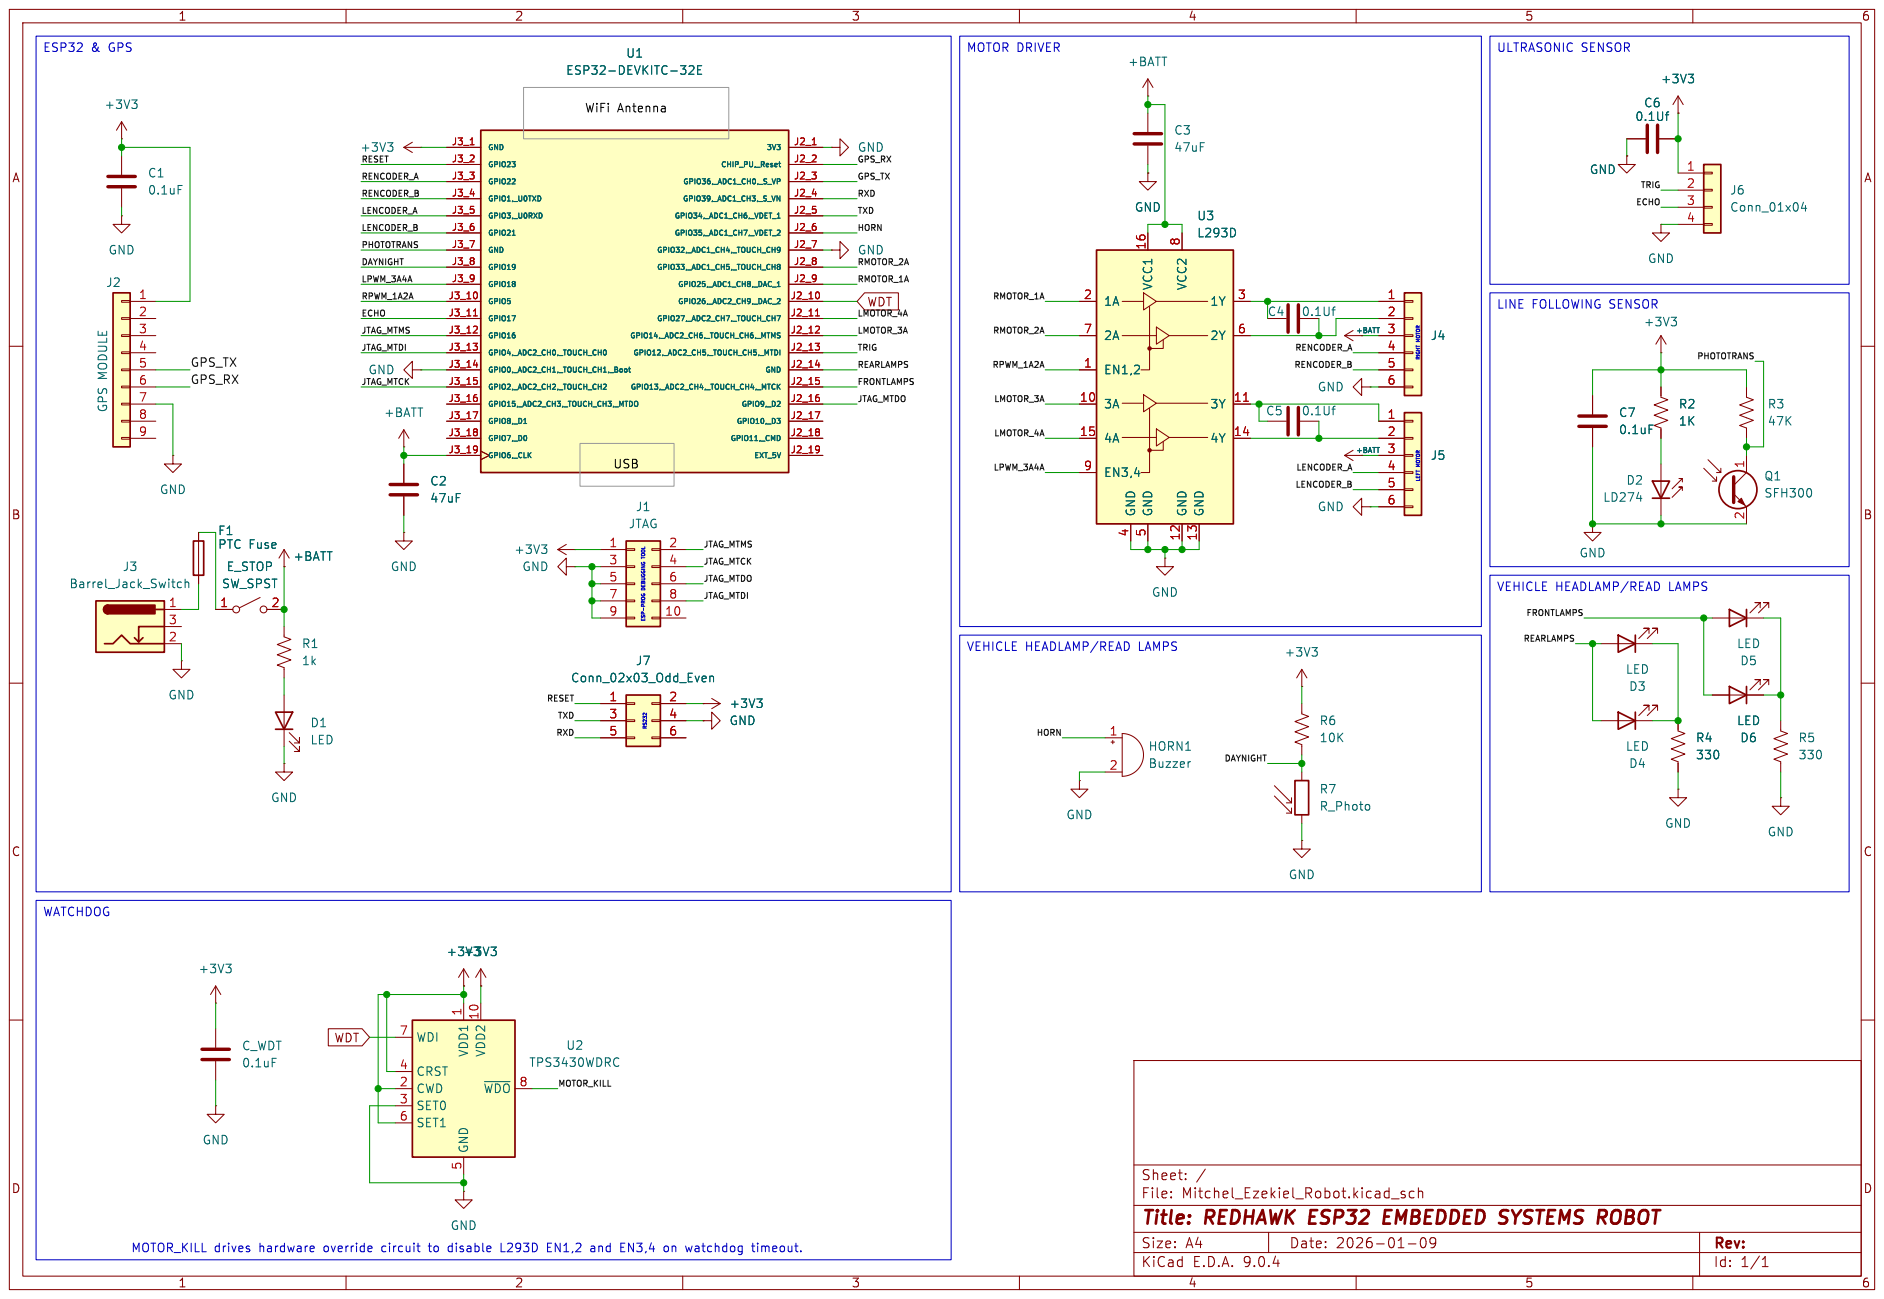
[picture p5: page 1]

1 2 Q1 SFH300 GND VDD2 10 WDI 7 CRST 4 CWD 2 SET0 3 SET1 6 VDD1

VEHICLE HEADLAMP/READ LAMPS

File: Mitchel_Ezekiel_Robot.kicad_sch Sheet: /
Id: 1/1 Title: REDHAWK ESP32 EMBEDDED SYSTEMS ROBOT

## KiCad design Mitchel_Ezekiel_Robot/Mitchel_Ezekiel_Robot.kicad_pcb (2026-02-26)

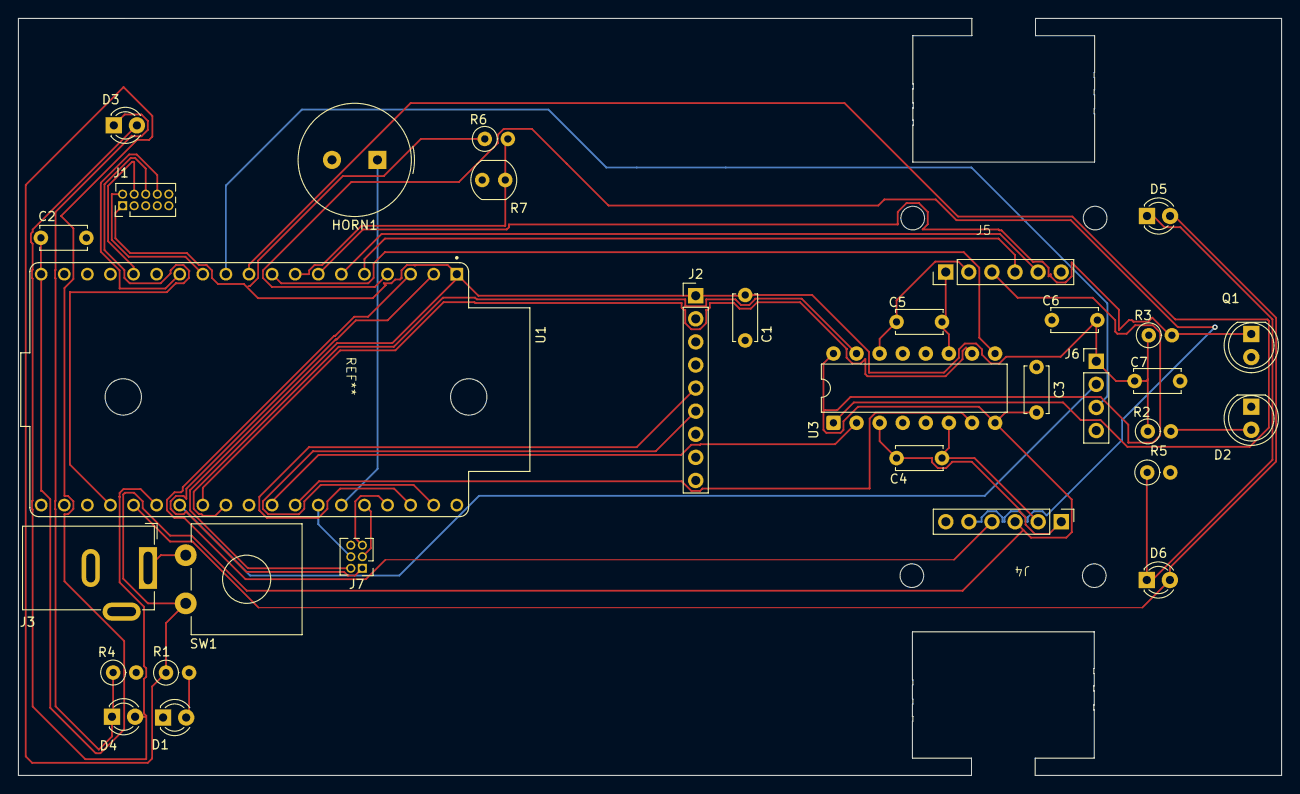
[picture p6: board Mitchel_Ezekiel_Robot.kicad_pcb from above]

Board: 2 copper layers, 138.9 x 83.3 mm, 32 parts (0 on the bottom side), 38 nets.

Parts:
C1, C7: 0.1uF; C_Disc_D5.0mm_W2.5mm_P5.00mm
C2, C3: 47uF; C_Disc_D5.0mm_W2.5mm_P5.00mm
C4, C5, C6: 0.1Uf; C_Disc_D5.0mm_W2.5mm_P5.00mm
D1, D3, D4, D5, D6: LED; LED_D3.0mm
D2: LD274; LED_D5.0mm_IRGrey
HORN1: Buzzer; Buzzer_TDK_PS1240P02BT_D12.2mm_H6.5mm
J1: JTAG; PinHeader_2x05_P1.27mm_Vertical
J2: GPS MODULE; PinHeader_1x09_P2.54mm_Vertical
J3: Barrel_Jack_Switch; BarrelJack_GCT_DCJ200-10-A_Horizontal
J4, J5: Conn_01x06; Pololu-3675-GearMotorWEncoder
J6: Conn_01x04; PinHeader_1x04_P2.54mm_Vertical
J7: Conn_02x03_Odd_Even; PinHeader_2x03_P1.27mm_Vertical
Q1: SFH300; LED_D5.0mm_Clear
R1: 1k; R_Axial_DIN0207_L6.3mm_D2.5mm_P2.54mm_Vertical
R2: 1K; R_Axial_DIN0207_L6.3mm_D2.5mm_P2.54mm_Vertical
R3: 47K; R_Axial_DIN0207_L6.3mm_D2.5mm_P2.54mm_Vertical
R4, R5: 330; R_Axial_DIN0207_L6.3mm_D2.5mm_P2.54mm_Vertical
R6: 10K; R_Axial_DIN0207_L6.3mm_D2.5mm_P2.54mm_Vertical
R7: R_Photo; R_LDR_4.9x4.2mm_P2.54mm_Vertical
SW1: SW_SPST; SW_CW_GPTS203211B
U1: ESP32-DEVKITC-32E; MODULE_ESP32-DEVKITC-32E
U3: L293D; DIP-16_W7.62mm

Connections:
+3V3: C1.1, C6.2, C7.1, J1.1, J2.1, J6.1, J7.2, R2.1, R3.1, R6.1, U1.J2_1 (3V3)
+BATT: C2.1, C3.1, J4.3, J5.3, R1.1, SW1.2 (B), U1.J2_19 (EXT_5V), U3.8 (VCC2), U3.16 (VCC1)
/DAYNIGHT: R6.2, R7.1, U1.J2_8 (GPIO33,_ADC1_CH5,_TOUCH_CH8)
/ECHO: J6.3, U1.J2_11 (GPIO27,_ADC2_CH7,_TOUCH_CH7)
/FRONTLAMPS: D5.2 (A), D6.2 (A), U1.J3_15 (GPIO2,_ADC2_CH2,_TOUCH_CH2)
/GPS_RX: J2.6, U1.J3_2 (GPIO23)
/GPS_TX: J2.5, U1.J3_3 (GPIO22)
/HORN: HORN1.1 (+), U1.J3_6 (GPIO21)
/JTAG_MTCK: J1.4, U1.J2_15 (GPIO13,_ADC2_CH4,_TOUCH_CH4,_MTCK)
/JTAG_MTDI: J1.8, U1.J2_13 (GPIO12,_ADC2_CH5,_TOUCH_CH5,_MTDI)
/JTAG_MTDO: J1.6, U1.J3_16 (GPIO15,_ADC2_CH3,_TOUCH_CH3,_MTDO)
/JTAG_MTMS: J1.2, U1.J2_12 (GPIO14,_ADC2_CH6,_TOUCH_CH6,_MTMS)
/LENCODER_A: J5.4, U1.J2_5 (GPIO34,_ADC1_CH6,_VDET_1)
/LENCODER_B: J5.5, U1.J2_6 (GPIO35,_ADC1_CH7,_VDET_2)
/LMOTOR_3A: U1.J3_12 (GPIO16), U3.10 (3A)
/LMOTOR_4A: U1.J3_11 (GPIO17), U3.15 (4A)
/LPWM_3A4A: U1.J2_9 (GPIO25,_ADC1_CH8,_DAC_1), U3.9 (EN3,4)
/PHOTOTRANS: Q1.1 (C), R3.2, U1.J2_7 (GPIO32,_ADC1_CH4,_TOUCH_CH9)
/REARLAMPS: D3.2 (A), D4.2 (A), U1.J3_14 (GPIO0,_ADC2_CH1,_TOUCH_CH1,_Boot)
/RENCODER_A: J4.4, U1.J2_3 (GPIO36,_ADC1_CH0,_S_VP)
/RENCODER_B: J4.5, U1.J2_4 (GPIO39,_ADC1_CH3,_S_VN)
/RESET: J7.1, U1.J2_2 (CHIP_PU,_Reset)
/RMOTOR_1A: U1.J3_9 (GPIO18), U3.2 (1A)
/RMOTOR_2A: U1.J3_8 (GPIO19), U3.7 (2A)
/RPWM_1A2A: U1.J2_10 (GPIO26,_ADC2_CH9,_DAC_2), U3.1 (EN1,2)
/RXD: J7.5, U1.J3_4 (GPIO1,_U0TXD)
/TRIG: J6.2, U1.J3_13 (GPIO4,_ADC2_CH0,_TOUCH_CH0)
/TXD: J7.3, U1.J3_5 (GPIO3,_U0RXD)
GND: C1.2, C2.2, C3.2, C6.1, C7.2, D1.1 (K), D2.1 (K), HORN1.2 (-), J1.3, J1.5, J1.7, J1.9, J2.7, J3.2, J4.6, J5.6, J6.4, J7.4, Q1.2 (E), R4.2, R5.2, R7.2, U1.J2_14 (GND), U1.J3_1 (GND), U1.J3_7 (GND), U3.4 (GND), U3.5 (GND), U3.12 (GND), U3.13 (GND)
unnamed: D1.2 (A), R1.2
unnamed: D2.2 (A), R2.2
unnamed: D3.1 (K), D4.1 (K), R4.1
unnamed: D5.1 (K), D6.1 (K), R5.1
unnamed: C4.1, J4.1, U3.3 (1Y)
unnamed: C4.2, J4.2, U3.6 (2Y)
unnamed: C5.1, J5.1, U3.11 (3Y)
unnamed: C5.2, J5.2, U3.14 (4Y)
unnamed: J3.1, SW1.1 (A)

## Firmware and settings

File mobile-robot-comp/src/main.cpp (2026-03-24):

/*
 * Ezekiel A. Mitchell
 * Embedded Systems — Robot Firmware (Combined)
 * Platform: ESP32-DevKitC (arduino-esp32 v3.x)
 *
 * Functional Tests (matching test-plan numbering):
 *   1. Horn          5 beeps (400 ms on / 300 ms off)
 *   2. LEDs          front/rear alternating, all on, all off
 *   3. Light Sensor  60 s ADC monitor
 *   4. Motors        left fwd/rev, right fwd/rev (1 s each)
 *   5. Line Sensor   transition detection (10 s window)
 *   6. Ultrasonic    5 distance readings (HC-SR04 on TRIG=4 / ECHO=27)
 *   7. Completion    fanfare
 *
 * Autonomous Mode:
 *   Maze Solve   — right-hand-rule with front ultrasonic
 *
 * Driver Mode:
 *   Web UI at http://<robot-ip>/ — hold-to-drive pad, speed slider,
 *   individual test buttons, mode switching, live sensor panel.
 *   Serial menu also available at 115200 baud.
 */

#include <Arduino.h>
#include <WiFi.h>
#include <WiFiUdp.h>
#include "config.h"
#include "web_control.h"

// Test results string — displayed on the web page
String testResults = "";

// Last ultrasonic reading (cm); updated every 200 ms in loop()
static long sonarCm = 0;

// Unique robot ID
int robotID = 13;

// UDP
#define UDP_PORT 4210
WiFiUDP udp;
char incomingPacket[255];

// Dance routine — triggered by UDP command
void dance() {
    Serial.println("Robot Dancing!");
    for (int i = 0; i < 6; i++) {
        digitalWrite(FRONTLAMPS, HIGH);
        digitalWrite(REARLAMPS,  LOW);
        ledcWrite(HORN_CH, HORN_DUTY);
        delay(200);
        digitalWrite(FRONTLAMPS, LOW);
        digitalWrite(REARLAMPS,  HIGH);
        ledcWrite(HORN_CH, 0);
        delay(200);
    }
    digitalWrite(REARLAMPS, LOW);
}

// Handle incoming UDP command string
void handleCommand(String cmd) {
    if (cmd == "DANCE_ALL") {
        dance();
    }
    if (cmd.startsWith("DANCE_")) {
        int target = cmd.substring(6).toInt();
        if (target == robotID) {
            dance();
        }
    }
}

// Motor helpers
void motorsStop() {
    ledcWrite(RMOTOR_CH, 0);
    ledcWrite(LMOTOR_CH, 0);
    digitalWrite(RMOTOR_1A, LOW); 
    digitalWrite(RMOTOR_2A, LOW);
    digitalWrite(LMOTOR_3A, LOW); 
    digitalWrite(LMOTOR_4A, LOW);
}

void driveForward(int spd) {
    digitalWrite(RMOTOR_1A, HIGH); 
    digitalWrite(RMOTOR_2A, LOW);
    digitalWrite(LMOTOR_3A, HIGH); 
    digitalWrite(LMOTOR_4A, LOW);
    ledcWrite(RMOTOR_CH, spd);
    ledcWrite(LMOTOR_CH, spd);
}

void driveReverse(int spd) {
    digitalWrite(RMOTOR_1A, LOW); 
    digitalWrite(RMOTOR_2A, HIGH);
    digitalWrite(LMOTOR_3A, LOW); 
    digitalWrite(LMOTOR_4A, HIGH);
    ledcWrite(RMOTOR_CH, spd);
    ledcWrite(LMOTOR_CH, spd);
}

// Pivot left:  right wheel forward, left wheel reverse
void pivotLeft(int spd) {
    digitalWrite(RMOTOR_1A, HIGH); 
    digitalWrite(RMOTOR_2A, LOW);
    digitalWrite(LMOTOR_3A, LOW);  
    digitalWrite(LMOTOR_4A, HIGH);
    ledcWrite(RMOTOR_CH, spd);
    ledcWrite(LMOTOR_CH, spd);
}

// Pivot right: left wheel forward, right wheel reverse
void pivotRight(int spd) {
    digitalWrite(RMOTOR_1A, LOW);  
    digitalWrite(RMOTOR_2A, HIGH);
    digitalWrite(LMOTOR_3A, HIGH); 
    digitalWrite(LMOTOR_4A, LOW);
    ledcWrite(RMOTOR_CH, spd);
    ledcWrite(LMOTOR_CH, spd);
}

// Gentle curve: inner wheel at half duty
static void curveLeft(int spd) {
    digitalWrite(RMOTOR_1A, HIGH); 
    digitalWrite(RMOTOR_2A, LOW);
    digitalWrite(LMOTOR_3A, HIGH); 
    digitalWrite(LMOTOR_4A, LOW);
    ledcWrite(RMOTOR_CH, spd);
    ledcWrite(LMOTOR_CH, spd / 4);
}
static void curveRight(int spd) {
    digitalWrite(RMOTOR_1A, HIGH); 
    digitalWrite(RMOTOR_2A, LOW);
    digitalWrite(LMOTOR_3A, HIGH); 
    digitalWrite(LMOTOR_4A, LOW);
    ledcWrite(RMOTOR_CH, spd / 4);
    ledcWrite(LMOTOR_CH, spd);
}

// Horn
void beep(int count, int onMs, int offMs) {
    for (int i = 0; i < count; i++) {
        ledcWrite(HORN_CH, HORN_DUTY);
        delay(onMs);
        ledcWrite(HORN_CH, 0);
        if (i < count - 1) delay(offMs);
    }
}

// Sensor helpers
static bool onLine() {
    return analogRead(IR_RECEIVE) > webThreshold;
}

static long readUltrasonic() {
    digitalWrite(TRIG, LOW);  
    delayMicroseconds(2);
    digitalWrite(TRIG, HIGH); 
    delayMicroseconds(10);
    digitalWrite(TRIG, LOW);
    return pulseIn(ECHO, HIGH, 25000UL) / 58L;
}

static void blinkLamp(int pin, int count, int onMs, int offMs) {
    for (int i = 0; i < count; i++) {
        digitalWrite(pin, HIGH); 
        delay(onMs);
        digitalWrite(pin, LOW);
        if (i < count - 1) delay(offMs);
    }
}

// Functional tests (test-plan numbering)
void testHorn() {
    Serial.println("TEST 1: Horn - 5 beeps (400 ms on / 300 ms off)");
    beep(5, 400, 300);
    delay(500);
    testResults += "TEST 1  Horn           PASS\n";
    Serial.println("  PASS\n");
}

void testLEDs() {
    Serial.println("TEST 2: LEDs - front/rear alternating, all on, all off");
    for (int i = 0; i < 3; i++) {
        digitalWrite(FRONTLAMPS, HIGH); 
        digitalWrite(REARLAMPS, LOW);  
        delay(400);
        digitalWrite(FRONTLAMPS, LOW);  
        digitalWrite(REARLAMPS, HIGH); 
        delay(400);
    }
    digitalWrite(FRONTLAMPS, HIGH); 
    digitalWrite(REARLAMPS, HIGH); 
    delay(500);
    digitalWrite(FRONTLAMPS, LOW);  
    digitalWrite(REARLAMPS, LOW);  
    delay(500);
    testResults += "TEST 2  LEDs           PASS\n";
    Serial.println("  PASS\n");
}

void testLightSensor() {
    Serial.println("TEST 3: Light Sensor - cover/uncover now (10 s)");
    beep(2, 100, 400);

    long sum = 0;
    for (int s = 0; s < 10; s++) { 
        sum += analogRead(DAYNIGHT); 
        delay(100); 
    }
    int baseline = (int)(sum / 10);
    Serial.print("  Baseline ADC = "); 
    Serial.println(baseline);

    unsigned long t0 = millis();
    while (millis() - t0 < 10000UL) {
        int reading = analogRead(DAYNIGHT);
        bool dark = abs(reading - baseline) > 200;
        digitalWrite(FRONTLAMPS, dark ? HIGH : LOW);
        digitalWrite(REARLAMPS,  dark ? HIGH : LOW);
        Serial.print("    ADC = "); 
        Serial.print(reading);
        Serial.println(dark ? "  [DARK]" : "  [LIGHT]");
        delay(500);
    }
    digitalWrite(FRONTLAMPS, LOW); 
    digitalWrite(REARLAMPS, LOW);
    testResults += "TEST 3  Light Sensor   PASS\n";
    Serial.println("  PASS\n");
}

void testMotors() {
    Serial.println("TEST 4: Motors - left fwd/rev, right fwd/rev (1 s each)");

    Serial.println("  Left  fwd");
    digitalWrite(LMOTOR_3A, HIGH); 
    digitalWrite(LMOTOR_4A, LOW);
    ledcWrite(LMOTOR_CH, MOTOR_FULL_DUTY); 
    delay(1000); motorsStop(); delay(300);

    Serial.println("  Left  rev");
    digitalWrite(LMOTOR_3A, LOW); 
    digitalWrite(LMOTOR_4A, HIGH);
    ledcWrite(LMOTOR_CH, MOTOR_FULL_DUTY); 
    delay(1000); motorsStop(); delay(300);

    Serial.println("  Right fwd");
    digitalWrite(RMOTOR_1A, HIGH); 
    digitalWrite(RMOTOR_2A, LOW);
    ledcWrite(RMOTOR_CH, MOTOR_FULL_DUTY); 
    delay(1000); 
    motorsStop(); 
    delay(300);

    Serial.println("  Right rev");
    digitalWrite(RMOTOR_1A, LOW); 
    digitalWrite(RMOTOR_2A, HIGH);
    ledcWrite(RMOTOR_CH, MOTOR_FULL_DUTY); 
    delay(1000); 
    motorsStop(); 
    delay(500);

    testResults += "TEST 4  Motors         PASS\n";
    Serial.println("  PASS\n");
}

void testLineSensor() {
    Serial.println("TEST 5: Line Sensor - place/remove line now (10 s)");
    beep(2, 200, 200);

    bool initialOnLine = onLine();
    Serial.print("  Initial state: "); Serial.print(initialOnLine ? "ON LINE" : "off line");
    Serial.print("  (analog="); Serial.print(analogRead(IR_RECEIVE));
    Serial.print(", threshold="); Serial.print(webThreshold); Serial.println(")");
    bool changed = false;
    unsigned long t0 = millis();
    while (millis() - t0 < 10000UL) {
        int aval = analogRead(IR_RECEIVE);
        bool state = onLine();
        Serial.print("  analog="); Serial.print(aval);
        Serial.println(state ? "  [ON LINE]" : "  [off line]");
        if (state != initialOnLine) { changed = true; break; }
        delay(500);
    }
    testResults += changed ? "TEST 5  Line Sensor    PASS\n"
                           : "TEST 5  Line Sensor    FAIL (no transition)\n";
    Serial.println(changed ? "  Transition detected - PASS\n" : "  No transition - FAIL\n");
    delay(500);
}

void testUltrasonic() {
    Serial.println("TEST 6: Ultrasonic distance sensor");
    bool ok = false;
    for (int i = 0; i < 5; i++) {
        long d = readUltrasonic();
        Serial.print("  Reading "); 
        Serial.print(i + 1); 
        Serial.print(": ");
        if (d > 0) { Serial.print(d);
            Serial.println(" cm");
            ok = true;
        } else {
            Serial.println("no echo");
        }
        delay(200);
    }
    testResults += ok ? "TEST 6  Ultrasonic     PASS\n"
                      : "TEST 6  Ultrasonic     FAIL (no echo)\n";
    Serial.println(ok ? "  PASS\n" : "  FAIL\n");
}

void runAllTests() {
    testResults = "";
    testHorn();
    testLEDs();
    testLightSensor();
    testMotors();
    testLineSensor();
    testUltrasonic();

    Serial.println("TEST 7: Completion - 15 fast beeps");
    beep(15, 80, 60);
    testResults += "TEST 7  Completion     PASS\n";
    Serial.println("  PASS\n");
    Serial.println("=== ALL TESTS COMPLETE ===\n");
}

// Autonomous: Maze Solve
static int mazeStuckCount = 0;

static void runMazeSolve() {
    long dist      = readUltrasonic();
    bool wallAhead = (dist > 0 && dist <= WALL_STOP_CM);
    bool lineAhead = onLine();   // black or red tape barrier — both absorb IR
    bool blocked   = wallAhead || lineAhead;

    if (!blocked) {
        driveForward(MAZE_SPEED);
        mazeStuckCount = 0;
        delay(80);
    } else {
        motorsStop();
        delay(100);
        mazeStuckCount++;

        // Back away from barrier before turning
        driveReverse(SPEED_SLOW);
        delay(lineAhead ? 450 : 250);   // back up further if line sensor triggered
        motorsStop();
        delay(100);

        if (mazeStuckCount > 8) {
            // Truly stuck — ~180° turn to escape
            pivotRight(SPEED_TURN);
            delay(TURN_90_MS * 2);
            motorsStop();
            mazeStuckCount = 0;
        } else {
            pivotRight(SPEED_TURN);
            delay(TURN_90_MS);
            motorsStop();
            delay(150);
        }

        if (lineAhead) {
            Serial.print("  Maze: tape barrier (black/red), turn ");
        } else {
            Serial.print("  Maze: wall obstacle ");
            Serial.print(dist);
            Serial.print(" cm, turn ");
        }
        Serial.println(mazeStuckCount);
    }
}

// Line sensor calibration — call with robot sitting ON the tape
void lineFollowCalibrate() {
    Serial.println("  LF calibrating — place robot ON the tape, holding still...");
    beep(1, 150, 0);
    delay(500);
    long sum = 0;
    for (int i = 0; i < 30; i++) {
        sum += analogRead(IR_RECEIVE);
        delay(10);
    }
    int tapePeak = (int)(sum / 30);
    webThreshold = tapePeak - 600;
    Serial.print("  LF tape reading="); Serial.print(tapePeak);
    Serial.print("  webThreshold="); Serial.print(webThreshold);
    Serial.print("  verify readback="); Serial.println((int)webThreshold);
    beep(2, 80, 80);
}

// Autonomous: Line Follow
static void runLineFollow() {
    int aval    = analogRead(IR_RECEIVE);
    bool onLine  = aval > (int)webThreshold;
    // Dark lines (red/black) absorb IR → high analog value → turn inward (steer right).
    // Light lines (green/blue) reflect more IR → lower analog value but still above
    // webThreshold → turn outward (steer left).
    bool darkLine = aval > LINE_COLOR_THRESHOLD;

    static int offCount  = 0;  // consecutive off-tape reads
    static int onStreak  = 0;  // consecutive on-tape reads (hysteresis)

    static int dbgCount = 0;
    if (++dbgCount >= 20) {
        dbgCount = 0;
        Serial.print("  LF analog="); Serial.print(aval);
        Serial.print(" thr="); Serial.print((int)webThreshold);
        Serial.print(" colorThr="); Serial.print(LINE_COLOR_THRESHOLD);
        Serial.print(onLine ? (darkLine ? "  [RED/BLACK]" : "  [GREEN/BLUE]") : "  [off line]");
        Serial.print("  streak="); Serial.print(onStreak);
        Serial.print("  offCount="); Serial.println(offCount);
    }

    digitalWrite(RMOTOR_1A, HIGH); digitalWrite(RMOTOR_2A, LOW);
    digitalWrite(LMOTOR_3A, HIGH); digitalWrite(LMOTOR_4A, LOW);

    if (onLine) {
        onStreak++;
        offCount = 0;

        if (onStreak >= 3) {
            // 3 consecutive on-tape reads — confirmed on line, steer by colour.
            digitalWrite(FRONTLAMPS, HIGH); digitalWrite(REARLAMPS, LOW);
            if (darkLine) {
                // Red/black — turn inward: slow right motor, left motor full
                ledcWrite(RMOTOR_CH, LINE_FOLLOW_SPEED / LINE_INNER_RATIO);
                ledcWrite(LMOTOR_CH, LINE_FOLLOW_SPEED);
            } else {
                // Green/blue — turn outward: slow left motor, right motor full
                ledcWrite(RMOTOR_CH, LINE_FOLLOW_SPEED);
                ledcWrite(LMOTOR_CH, LINE_FOLLOW_SPEED / LINE_INNER_RATIO);
            }
        } else {
            // Still in confirmation window — hold recovery pivot so a stray edge
            // reading doesn't prematurely flip us back to steering away from tape
            ledcWrite(RMOTOR_CH, LINE_FOLLOW_SPEED);
            ledcWrite(LMOTOR_CH, 0);
        }
    } else {
        onStreak = 0;
        offCount++;
        digitalWrite(FRONTLAMPS, LOW); digitalWrite(REARLAMPS, HIGH);

        // Hard pivot left — outer wheel full, inner stopped.
        // Hold this turn continuously until the line is re-acquired.
        ledcWrite(RMOTOR_CH, LINE_FOLLOW_SPEED);
        ledcWrite(LMOTOR_CH, 0);
    }
    delay(15);
}

// Serial menu
static void printMenu() {;
    Serial.println("    Robot Serial Menu:    ");
    Serial.println("|========================|");
    Serial.println("1-6  Run individual test");
    Serial.println("A    Run all tests");
    Serial.println("M    Manual (web driver)");
    Serial.println("Z    Maze-solve mode");
    Serial.println("L    Line-follow mode");
    Serial.println("S    Stop / idle");
    Serial.print("Select: ");
}

static void handleSerial() {
    if (!Serial.available()) return;
    char c = (char)Serial.read();
    while (Serial.available()) Serial.read();
    Serial.println(c); Serial.println();

    robotMode = MODE_IDLE;
    motorsStop();

    switch (c) {
        case '1': testHorn(); 
        break;
        case '2': testLEDs(); 
        break;
        case '3': testLightSensor(); 
        break;
        case '4': testMotors(); 
        break;
        case '5': testLineSensor(); 
        break;
        case '6': testUltrasonic(); 
        break;
        case 'A': case 'a': runAllTests(); 
        break;
        case 'M': case 'm':
            robotMode = MODE_MANUAL;
            Serial.println(">> Manual (driver) mode"); break;
        case 'Z': case 'z':
            robotMode = MODE_MAZE_SOLVE;
            mazeStuckCount = 0;
            beep(3, 80, 80);
            Serial.println(">> Maze-solve mode started"); break;
        case 'L': case 'l':
            lineFollowCalibrate();
            robotMode = MODE_LINE_FOLLOW;
            Serial.println(">> Line-follow mode started"); break;
        case 'S': case 's':
            Serial.println(">> Stopped / idle"); break;
        default: break;
    }
    printMenu();
}

// setup
void setup() {
    Serial.begin(115200);
    delay(500);
    Serial.println("\n=== Robot Firmware (Combined) ===");

    // Outputs
    pinMode(RMOTOR_1A, OUTPUT); 
    pinMode(RMOTOR_2A, OUTPUT);
    pinMode(LMOTOR_3A, OUTPUT); 
    pinMode(LMOTOR_4A, OUTPUT);
    pinMode(FRONTLAMPS, OUTPUT); 
    pinMode(REARLAMPS, OUTPUT);
    pinMode(STATUS_LED, OUTPUT); 
    digitalWrite(STATUS_LED, LOW);
    pinMode(TRIG, OUTPUT);       
    digitalWrite(TRIG, LOW);

    // Inputs
    pinMode(ECHO, INPUT);
    pinMode(IR_RECEIVE, INPUT_PULLUP);
    pinMode(RENCODER_A, INPUT_PULLUP); 
    pinMode(RENCODER_B, INPUT_PULLUP);
    pinMode(LENCODER_A, INPUT_PULLUP); 
    pinMode(LENCODER_B, INPUT_PULLUP);

    // LEDC PWM channels
    ledcSetup(HORN_CH, HORN_FREQ, HORN_RES);  
    ledcAttachPin(HORN, HORN_CH);
    ledcSetup(RMOTOR_CH, MOTOR_FREQ, MOTOR_RES); 
    ledcAttachPin(RPWM_1A2A, RMOTOR_CH);
    ledcSetup(LMOTOR_CH, MOTOR_FREQ, MOTOR_RES); 
    ledcAttachPin(LPWM_3A4A, LMOTOR_CH);

    ledcWrite(HORN_CH, 0);
    motorsStop();
    digitalWrite(FRONTLAMPS, LOW); 
    digitalWrite(REARLAMPS, LOW);
    analogReadResolution(12);
    delay(1000);

    // Wi-Fi
    Serial.print("Connecting to '"); 
    Serial.print(WIFI_SSID); Serial.println("'...");
    WiFi.mode(WIFI_STA);
    WiFi.begin(WIFI_SSID, WIFI_PASS);

    unsigned long t0 = millis();
    while (WiFi.status() != WL_CONNECTED && millis() - t0 < 20000UL) {
        digitalWrite(STATUS_LED, !digitalRead(STATUS_LED));
        delay(500);
    }

    if (WiFi.status() == WL_CONNECTED) {
        digitalWrite(STATUS_LED, HIGH);
        Serial.print("  Connected → open http://");
        Serial.print(WiFi.localIP());
        Serial.println("/ in your browser or phone.");
        testResults += "EC      WiFi+WebServer  PASS (IP: " + WiFi.localIP().toString() + ")\n";
        setupWebServer();
        udp.begin(UDP_PORT);
        Serial.print("  UDP listening on port ");
        Serial.println(UDP_PORT);
    } else {
        Serial.println("  Wi-Fi failed — continuing offline.");
        testResults += "EC      WiFi+WebServer  FAIL (timeout)\n";
        for (int i = 0; i < 20; i++) {
            digitalWrite(STATUS_LED, !digitalRead(STATUS_LED)); delay(200);
        }
        digitalWrite(STATUS_LED, LOW);
    }

    Serial.println();
    printMenu();
}

// loop
void loop() {
    // UDP command listener
    int packetSize = udp.parsePacket();
    if (packetSize) {
        int len = udp.read(incomingPacket, 255);
        if (len > 0) incomingPacket[len] = 0;
        handleCommand(String(incomingPacket));
    }

    webServerLoop();
    handleSerial();

    // Sonar: poll every 200 ms (skip modes that do their own reads or need tight timing)
    static unsigned long lastSonarMs = 0;
    if (robotMode != MODE_MAZE_SOLVE && robotMode != MODE_LINE_FOLLOW && millis() - lastSonarMs >= 200) {
        sonarCm = readUltrasonic();
        lastSonarMs = millis();
    }

    switch (robotMode) {

        case MODE_IDLE:
            break;

        case MODE_MANUAL:
            // Watchdog: stop motors if web commands have gone quiet
            if (millis() - lastWebCmd > WEB_WATCHDOG_MS) {
                motorsStop();
            }
            break;

        case MODE_MAZE_SOLVE:
            runMazeSolve();
            break;

        case MODE_LINE_FOLLOW:
            runLineFollow();
            break;
    }
}

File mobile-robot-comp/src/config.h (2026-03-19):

#pragma once

// Right motor (L293D EN1 / 1A / 2A)
#define RMOTOR_1A 18
#define RMOTOR_2A 19
#define RPWM_1A2A 26

// Left motor (L293D EN3 / 3A / 4A)
#define LMOTOR_3A 16
#define LMOTOR_4A 17
#define LPWM_3A4A 25

// Encoders - quadrature, open-drain, INPUT_PULLUP required
#define RENCODER_A 36
#define RENCODER_B 39
#define LENCODER_A 34
#define LENCODER_B 35

// Horn
#define HORN 21

// Lighting
#define FRONTLAMPS 2
#define REARLAMPS 0

// Sensors
#define DAYNIGHT 33
#define IR_RECEIVE 32

// Ultrasonic (HC-SR04) — TRIG=4, ECHO=27
// Wiring: VCC → 5 V, GND → GND, TRIG → GPIO 4, ECHO → GPIO 27
#define TRIG 4
#define ECHO 27

// Status LED
#define STATUS_LED 5

// PWM parameters
#define HORN_FREQ 1000
#define HORN_RES 8
#define HORN_DUTY 128

#define MOTOR_FREQ 5000
#define MOTOR_RES 8
#define MOTOR_FULL_DUTY 255

#define HORN_CH 0
#define RMOTOR_CH 1
#define LMOTOR_CH 2

// Wi-Fi credentials (station mode - not used when running as soft AP)
#define WIFI_SSID "SU-ECE-LAB"
#define WIFI_PASS "FaraDay8086!"


// Access point credentials (ESP32 hosts the network)
#define AP_SSID "ezekielRobot"
#define AP_PASS "password123"  // leave empty for open network

// Autonomous mode tuning

// Line sensor polarity: 0 = LOW over line, 1 = HIGH over line
#define LINE_DETECT_LEVEL  0

// Motor duty cycles (0-255)
#define SPEED_SLOW 140
#define SPEED_MED 180
#define SPEED_FAST 220
#define SPEED_TURN 155

// Maze solver
#define MAZE_SPEED SPEED_FAST
#define WALL_STOP_CM 18    // stop & turn when obstacle ≤ this
#define TURN_90_MS 430    // time for ~90° pivot at SPEED_TURN

// Tune by running test 5 and observing on-tape vs off-tape analog values.
#define LINE_SENSOR_THRESHOLD  650

// Line follower (single IR sensor — bang-bang edge tracking)
#define LINE_FOLLOW_SPEED  SPEED_MED  // base drive speed while following
#define LINE_INNER_RATIO   4          // inner-wheel divisor for gentle curves (1=pivot, 2=moderate, 4=gentle)

// Color-based steering: readings above this = dark line (red/black → turn inward);
// readings between webThreshold and this = light line (green/blue → turn outward).
// Tune by observing analog values for each tape colour at runtime.
#define LINE_COLOR_THRESHOLD  2500

// Web watchdog: stop motors if no /drive command within this window (ms)
#define WEB_WATCHDOG_MS 600

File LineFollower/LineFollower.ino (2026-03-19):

// ---------------- Pin Definitions ----------------

// Phototransistor (confirm PIN definitions with the schematic) 
#define PHOTOTRANS_PIN  32

// L293D Motor Driver Pins
#define RMOTOR_1A   18
#define RMOTOR_2A   19
#define RPWM_1A2A   5

#define LMOTOR_3A   16
#define LMOTOR_4A   17
#define LPWM_3A4A   4

// -------------------------------------------------

int lineValue;
int threshold = 2000;   // Intentionally incorrect
String currentState = "STOP";

void setup() {
  Serial.begin(115200);

  pinMode(PHOTOTRANS_PIN, INPUT);

  pinMode(RMOTOR_1A, OUTPUT);
  pinMode(RMOTOR_2A, OUTPUT);
  pinMode(LMOTOR_3A, OUTPUT);
  pinMode(LMOTOR_4A, OUTPUT);

  pinMode(RPWM_1A2A, OUTPUT);
  pinMode(LPWM_3A4A, OUTPUT);

  analogWrite(RPWM_1A2A, 150);
  analogWrite(LPWM_3A4A, 150);
}

// ---------------- Motor Functions ----------------

void moveForward() {
  digitalWrite(RMOTOR_1A, HIGH);
  digitalWrite(RMOTOR_2A, LOW);
  digitalWrite(LMOTOR_3A, HIGH);
  digitalWrite(LMOTOR_4A, LOW);
  currentState = "FORWARD";
}

void searchRight() {
  digitalWrite(RMOTOR_1A, LOW);
  digitalWrite(RMOTOR_2A, HIGH);
  digitalWrite(LMOTOR_3A, HIGH);
  digitalWrite(LMOTOR_4A, LOW);
  currentState = "SEARCH";
}

void stopRobot() {
  digitalWrite(RMOTOR_1A, LOW);
  digitalWrite(RMOTOR_2A, LOW);
  digitalWrite(LMOTOR_3A, LOW);
  digitalWrite(LMOTOR_4A, LOW);
  currentState = "STOP";
}

// ---------------- Main Loop ----------------

void loop() {

  lineValue = analogRead(PHOTOTRANS_PIN);

  Serial.print("Sensor: ");
  Serial.print(lineValue);
  Serial.print("  State: ");
  Serial.println(currentState);

  // -------- FAULTY LOGIC --------

  if (lineValue < threshold) {
    moveForward();
  }
  else {
    searchRight();   // Always searches right (intentional flaw)
  }

  delay(200);   // Slow reaction (intentional flaw)
}

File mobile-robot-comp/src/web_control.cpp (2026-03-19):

#include "web_control.h"
#include "config.h"
#include <WebServer.h>

// Shared state definitions
volatile RobotMode      robotMode     = MODE_IDLE;
volatile int            webSpeed      = MOTOR_FULL_DUTY;
volatile int            webThreshold  = LINE_SENSOR_THRESHOLD;
volatile unsigned long  lastWebCmd    = 0;

// Hardware helpers defined in main.cpp
void beep(int count, int onMs, int offMs);
void motorsStop();
void lineFollowCalibrate();
void driveForward(int spd);
void driveReverse(int spd);
void pivotLeft(int spd);
void pivotRight(int spd);

// Test functions defined in main.cpp
void testHorn();
void testLEDs();
void testLightSensor();
void testMotors();
void testLineSensor();
void testUltrasonic();
void runAllTests();

static WebServer server(80);

// Root page (unified UI)
static void handleRoot()
{
    String html = R"rawliteral(
<!DOCTYPE html>
<html><head>
  <meta charset="UTF-8">
  <meta name="viewport" content="width=device-width,initial-scale=1">
  <title>Robot Control</title>
  <style>
    *      { box-sizing:border-box; }
    body   { font-family:sans-serif; background:#111; color:#eee;
             max-width:480px; margin:auto; padding:12px; }
    h1     { text-align:center; color:#4cf; margin:4px 0 10px; }
    h2     { color:#aef; border-bottom:1px solid #333; padding-bottom:3px;
             margin:14px 0 6px; font-size:1rem; }
    .row   { display:flex; gap:6px; margin:4px 0; }
    button { flex:1; padding:13px 4px; font-size:0.9rem; border:none;
             border-radius:8px; cursor:pointer; background:#4cf;
             color:#111; font-weight:bold; user-select:none;
             -webkit-user-select:none; }
    button:active { opacity:0.65; }
    .red   { background:#f55 !important; color:#fff !important; }
    .grn   { background:#5d5 !important; color:#111 !important; }
    .gray  { background:#555 !important; color:#eee !important; }
    .amber { background:#fa4 !important; color:#111 !important; }
    #status{ text-align:center; background:#222; border-radius:6px;
             padding:7px; margin:6px 0; color:#fa4; font-weight:bold; }
    pre    { background:#222; padding:10px; border-radius:6px;
             font-size:0.75rem; white-space:pre-wrap; max-height:180px;
             overflow-y:auto; margin:4px 0; }
    label  { font-size:0.82rem; color:#aaa; display:block; margin-top:6px; }
    input[type=range] { width:100%; }
  </style>
  <script>
    let lastDir = '', lastSpd = 0;
    let lastCmdTime = 0;
    const CMD_INTERVAL_MS = 80; // max ~12 commands/sec

    function cmd(path, cb) {
      fetch(path).then(r => r.text()).then(t => {
        document.getElementById('status').innerText = t;
        if (cb) cb(t);
      });
    }

    // Virtual thumb joystick
    const JOY = (() => {
      let canvas, ctx, cx, cy, outerR, nubR = 32;
      let active = false, jX, jY;

      function draw() {
        ctx.clearRect(0, 0, canvas.width, canvas.height);
        // outer ring
        ctx.beginPath(); ctx.arc(cx, cy, outerR, 0, Math.PI*2);
        ctx.strokeStyle = '#4cf'; ctx.lineWidth = 3; ctx.stroke();
        ctx.fillStyle = 'rgba(68,204,255,0.07)'; ctx.fill();
        // direction labels
        ctx.fillStyle = '#4cf'; ctx.font = '14px sans-serif'; ctx.textAlign = 'center';
        ctx.fillText('\u25b2', cx, cy - outerR + 18);
        ctx.fillText('\u25bc', cx, cy + outerR - 6);
        ctx.fillText('\u25c4', cx - outerR + 12, cy + 5);
        ctx.fillText('\u25ba', cx + outerR - 8, cy + 5);
        // nub
        ctx.beginPath(); ctx.arc(jX, jY, nubR, 0, Math.PI*2);
        ctx.fillStyle = active ? '#4cf' : '#555'; ctx.fill();
        ctx.strokeStyle = active ? '#9ef' : '#888'; ctx.lineWidth = 2; ctx.stroke();
      }

      function calcCmd(dx, dy) {
        const dist = Math.sqrt(dx*dx + dy*dy);
        if (dist < outerR * 0.15) return {dir:'stop', spd:0};
        const maxSpd = parseInt(document.getElementById('spd').value);
        const t = Math.min((dist - outerR * 0.15) / (outerR * 0.85), 1); // smooth ramp from dead zone edge
        const spd = Math.round((60 + (maxSpd - 60) * t) / 5) * 5; // quantize to ±5 to suppress micro-updates
        const dir = Math.abs(dy) >= Math.abs(dx)
          ? (dy < 0 ? 'fwd' : 'rev')
          : (dx > 0 ? 'right' : 'left');
        return {dir, spd};
      }

      function sendCmd(dx, dy) {
        const {dir, spd} = calcCmd(dx, dy);
        const now = Date.now();
        if (dir === lastDir && spd === lastSpd) return;
        if (now - lastCmdTime < CMD_INTERVAL_MS) return; // rate limit
        lastDir = dir; lastSpd = spd; lastCmdTime = now;
        cmd('/drive/' + dir + (dir !== 'stop' ? '?spd=' + spd : ''));
      }

      function move(clientX, clientY) {
        const rect = canvas.getBoundingClientRect();
        let dx = clientX - rect.left - cx;
        let dy = clientY - rect.top - cy;
        const dist = Math.sqrt(dx*dx + dy*dy);
        if (dist > outerR) { dx = dx/dist*outerR; dy = dy/dist*outerR; }
        jX = cx + dx; jY = cy + dy;
        sendCmd(dx, dy); draw();
      }

      function release() {
        active = false; jX = cx; jY = cy;
        if (lastDir !== 'stop') { lastDir = 'stop'; lastSpd = 0; cmd('/drive/stop'); }
        draw();
      }

      return {
        init() {
          canvas = document.getElementById('joystick');
          ctx = canvas.getContext('2d');
          cx = canvas.width/2; cy = canvas.height/2;
          outerR = cx - 14; jX = cx; jY = cy;
          draw();
          canvas.addEventListener('mousedown', e => { active=true; move(e.clientX,e.clientY); });
          canvas.addEventListener('mousemove', e => { if(active) move(e.clientX,e.clientY); });
          ['mouseup','mouseleave'].forEach(ev => canvas.addEventListener(ev, release));
          canvas.addEventListener('touchstart', e => {
            e.preventDefault(); active=true; move(e.touches[0].clientX,e.touches[0].clientY);
          }, {passive:false});
          canvas.addEventListener('touchmove', e => {
            e.preventDefault(); move(e.touches[0].clientX,e.touches[0].clientY);
          }, {passive:false});
          ['touchend','touchcancel'].forEach(ev =>
            canvas.addEventListener(ev, e => { e.preventDefault(); release(); }, {passive:false}));
        }
      };
    })();

    function pollSensors() {
      fetch('/sensors').then(r => r.text()).then(t =>
        document.getElementById('sensorBox').innerText = t);
    }

    window.onload = () => {
      JOY.init();
      setInterval(pollSensors, 1800);
      pollSensors();
    };
  </script>
</head><body>
  <h1>&#129302; Ezekiel's Robot</h1>
  <div id="status">Ready</div>
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

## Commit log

2026-01-09 mitchell robot 1 completion
    [Mitchel_Ezekiel_Robot.kicad_pcb, Mitchel_Ezekiel_Robot.kicad_sch]
2026-01-20 Robot Car Schematic Completion
    Complete schematic for robotic car
    [Ezekiel_Mitchell_ESP32_Robot_Schematic.kicad_sch, Mitchel_Ezekiel_Robot.kicad_pcb, Mitchel_Ezekiel_Robot.kicad_sch]
2026-01-20 Add robot outline footprint to PCB design
    Added the 'Basic-Robot-Outline_1' footprint to Mitchel_Ezekiel_Robot.kicad_pcb, including edge cuts and fabrication details. Updated backup files to reflect the latest PCB changes and removed outdate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
2026-01-21 Update PCB layout and add new backup files
    Added four new backup ZIP files. Updated component placements and properties in Mitchel_Ezekiel_Robot.kicad_pcb, including changes to footprints, positions, and silkscreen details. Removed autosave a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
    [Mitchel_Ezekiel_Robot.kicad_pcb]
2026-01-21 gerber complete -- maybe...
    [Mitchel_Ezekiel_Robot.kicad_pcb]
2026-02-24 pcb stage + images
    [Mitchel_Ezekiel_Robot.kicad_pcb]
2026-02-25 pcb edit
    [Mitchel_Ezekiel_Robot.kicad_pcb]
2026-02-25 Clarify KiCad usage in project description
    Updated description to clarify the use of KiCad.
2026-02-25 readme update
    [Mitchel_Ezekiel_Robot.kicad_pcb]
2026-02-26 pcb gnd short fix
2026-02-26 update pcb edit
    [Ezekiel_Mitchell_ESP32_Robot_Schematic.kicad_pcb]
2026-02-26 caster insert
    [Ezekiel_Mitchell_ESP32_Robot_Schematic.kicad_pcb]
2026-03-11 fix test plan - config
    [main.cpp]
2026-03-11 change wifi to local + fix led off timing issue
    [config.h, main.cpp, web_control.cpp]
2026-03-13 error in line folloing
    [config.h, main.cpp]
2026-03-15 remove line following function -- bug overload
    [config.h, main.cpp, web_control.cpp]
2026-03-15 watchdog - threshold bar - line error
    [Mitchel_Ezekiel_Robot.kicad_sch]
2026-03-16 line follow bug fix
    [config.h, main.cpp]
